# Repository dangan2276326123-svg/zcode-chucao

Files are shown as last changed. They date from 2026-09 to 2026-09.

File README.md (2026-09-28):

# 纯视觉芍药行间除草机器人

本项目为纯视觉（单目相机，无 RTK/激光雷达）芍药行间除草机器人的完整工程：包括 DeepLabV3+ 语义分割训练、相机标定与 IPM 逆透视变换、导航控制、上位机（PC）主控循环、车端（树莓派）桥接与下位机（STM32）固件。

## 逐文件说明

### 根目录

| 文件 | 说明 |
|---|---|
| `README.md` | 本文件：目录/文件说明 + 快速上手 |
| `AGENTS.md` | AI 协作（ZCode/Agent）工作约定 |
| `.gitignore` | git 忽略规则（视频、抽帧、标定图、权重、抽帧、标定图、权重等（Keil OBJ 编译产物已另行清理出库）） |

### `common/` — PC/车端共用的 Python 模块

| 文件 | 说明 |
|---|---|
| `protocol.py` | 串口通信协议（帧格式、CRC、命令字），与下位机 `firmware/protocol.c` 一一对应 |
| `uart_vectors.py` | 控制量/状态量的串口向量编解码 |

### `network/` — 深度学习与感知算法

| 文件 | 说明 |
|---|---|
| `train_m.py` | **主分割模型训练入口**（DeepLabV3+ MobileNetV2，960×720，二分类：背景/杂草） |
| `train_h.py` / `train_r.py` / `train_x.py` | 其他骨干/配置的实验训练脚本（h/r/x 变体） |
| `train_metric_log.csv`（及 `_backup`） | 训练过程指标日志 |
| `modeling.py` | DeepLabV3+ 模型组装（选 backbone、ASPP、解码器） |
| `_deeplab.py` | DeepLabV3+ 核心结构实现（ASPP、Decoder） |
| `backbone/mobilenetv2.py` | MobileNetV2 骨干（主用） |
| `backbone/resnet.py` | ResNet 骨干（备选） |
| `backbone/xception.py` | Xception 骨干（备选） |
| `backbone/hrnetv2.py` | HRNetV2 骨干（备选） |
| `camera_calib.py` | 相机标定适配器：加载 `data/calib_params.npz`，去畸变 + IPM 逆透视（输出 960×720 物理坐标掩码） |
| `nav_control.py` | 导航控制：行中心线偏差/航向误差 → 差速控制量 |
| `local_single_station.py` | 本地单工位端到端链路：标定→分割→后处理→IPM→控制，用于整链自测 |
| `predict_demo.py` | 单张/文件夹推理演示（可视化叠加） |
| `utils.py` | 数据集加载、指标（mIoU）、损失等训练辅助 |

### `pc/` — 上位机（笔记本电脑）主控

| 文件 | 说明 |
|---|---|
| `main.py` | **完整控制循环入口**：`--source` replay 模式 / `--live` 实车模式，GUI 叠加显示，ESTOP 急停联锁 |
| `replay.py` | 对视频/图片目录逐帧回放推理并保存结果（离线验证） |
| `perception.py` | 感知封装：加载权重与标定 → 去畸变 → 分割 → IPM 鸟瞰 → **导航线拟合**（远场 `peony_postprocess` + `fit_centerline_lsq_weighted` 给底盘导航；近场 `peony_postprocess` 给中间刀 PID） |
| `control.py` | 控制层 4 个纯 Python 类（无 torch/cv2 依赖，各带单元测试）：`MiddleToolPID` 近场横向误差 → 中间刀滑台偏移（条件积分抗饱和，输出限幅 ±50mm）；`LatencyCompensator` 链路时延估计（滚动 p50/p95）+ 误差前移补偿 err+rate·delay；`LatErrorRate` 横向误差变化率估计（有限差分 + 平滑，供上者）；`DifferentialDrive` 底盘差速：远场横向误差+航向阻尼 → 左右轮速 v∓dv（标称 0.14 m/s，限幅 ±0.2）。⚠️ 过渡态：实车有四轮转向伺服但固件在 AUTO 锁直，按纯差速走；四轮转向+差速混合重写未做（缺口清单 P0-1），电流前馈也未实现（F4） |
| `state_machine.py` | 作业状态机（待机/作业/掉头/急停等状态切换） |
| `status_rx.py` | MCU STATUS 接收（live 模式，UDP 9100）：坏帧捕获计数绝不裸抛（D7 约束），滚动 1 秒 ≥5 坏帧报警（多半是固件/Python 协议字段失同步）；纯逻辑类，socket 留在 main |
| `ipm_io.py` | **IPM 外参加载器（带来源校验）**：拒绝无来源字段、`points_source != field`、源图近乎纯色/全黑、重投影超 2 cm、点数 <4、**车辆档案不匹配**的标定文件。存在的原因：仓库里那份 `results/smoke_ipm/ipm_params.json` 看着像标定，其实源图全黑（mean=0/std=0），只是求解器的冒烟测试 |

### `vehicle/` — 车端（树莓派）

| 文件 | 说明 |
|---|---|
| `stream_pi.py` | 树莓派上抓取相机图像并回传给上位机 |
| `bridge.py` | PC ↔ 下位机桥接：把上位机控制量经串口转给 STM32，回传状态 |
| `config.yaml` | 车端配置（PI_IP、串口号等） |

### `tools/` — 数据处理脚本

| 文件 | 说明 |
|---|---|
| `bench_status.py` | **B1/B2 台架验收记录器**：收 MCU 的 STATUS 帧（UDP 9100，复用 `pc/status_rx.StatusReceiver`，与生产同一套新鲜度/乱序/重启重同步判据），按绝对时间戳把每帧、每次**模式跳变**、每段**静默 gap**（成对 gap_start/gap_end ＋ 时长）和**你敲的场景标记**写进同一张 CSV。用途是把"失联几秒停车、夺权后刀具动不动"这类几秒内的瞬时行为变成可回看的证据。⚠️ 它**不测**横向偏差的米制数值（感知侧占位几何未接线）；CSV 里的 `current_a`/`batt_v` 两列固件是占位值（`retrofit.c:226` 写死 48.0f），只能看趋势不能当实测。X5 侧 `vehicle/config.yaml` 的 `pc_ip` 必须指到本机，否则收不到帧——那不是 MCU 的错。 |
| `check_dataset.py` | 数据集完整性检查（图/mask 对齐、类别统计） |
| `json2mask.py` | 标注 JSON → 训练用灰度 mask |
| `morph_process.py` | 分割结果后处理 + **导航线拟合**（被 `pc/perception.py` 和 `network/local_single_station.py` 导入）：`extract_dual_walls` 从 IPM 鸟瞰掩膜提取左右垄墙 → `fit_centerline_lsq` 对双墙各拟合 x=a·y+b 取中点 → `fit_centerline_lsq_weighted` 裁剪最小二乘 + 按内点率加权融合（遮挡鲁棒，单墙退化时门控回退）→ 输出 lookahead 行的横向偏差 `center_x` |
| `split_dataset.py` | **数据集划分（分组模式）**：按 视频/地块/日期 前缀整组划分，杜绝邻帧跨集合（H1.3）；冻结 `split_manifest.json`；硬性保证 train/val/test 各≥1 组，组数 <3 直接拒绝而非静默退回逐图；源目录先校验后清空，`--force` 才清目标 |
| `check_doc_invariants.py` | **文档不变量检查器**：执行 AGENTS 审查清单第 2 条 b) 项的"全仓枚举圈号区间并打印命中数"。扫描范围按 09-22 定案**摘除审查清单第 2 条所在行块**（规则自己的反例举例不计入，否则它永远红）。退出码 0=干净／1=禁用语义命中／2=基线漂移需解释／3=有 md 读不进去（**读不到就不算零命中**，防止假通过）。数法按**出现次数**、不按行数，两者都印。 |
| `geometry_check.py` | **整车空间口径判据（只报事实，不报结论）**：要 N 把刀各进一条等距草带，车宽至少 `(N−1)·s + 刀宽`。`track_span` 给"轮距等于几个行距／离整行距还差多少／几何上是否可能对得上行"，**不输出压苗结论**——旧版那句"车宽>行距即压在作物行上"是 09-21 复审撤回的过度推论（行距 38.2 时轮距 191 恰为 5 个行距，两轮正落在行间）；判压苗要另量胎宽（M14）与轮迹对行线偏差（M15）。`slide_reach_verdict` 按"总行程 = 2 × 单侧需求"判够不够（旧实现拿总行程跟单侧比，会把 30 cm 报成够）。未实测的量返回"不下结论"，不补默认值。配合 `docs/整车尺寸实测表_20260921.md` |
| `pre_annotate.py` | **半自动预标注**（DeepLabV3+ → labelme JSON + 叠加目检图）：qoder 工作区版，缺依赖时打人话提示、输出默认锁在工作区内、打印权重 md5/mtime 与解释器路径。原脚本在只读仓 `chucao_prj/annotation_tools/`，不改它 |
| `启动预标注.bat` | 预标注启动入口（写死可用解释器）。**故意只写 ASCII**：.bat 里的中文必须 GBK 编码，否则 cmd 显示乱码 |

### 运行环境 — 用哪个解释器（09-21 实测，别再猜）

| 用途 | 解释器 | 已验证 |
|---|---|---|
| 训练 / 预标注 / 感知推理 | `D:\ruanjian\anac\envs\deeplab\python.exe`（conda env `deeplab`，Python 3.9.23） | numpy 2.0.2、cv2 5.0.0、torch 2.6.0+cu124、torchvision 0.21.0、albumentations 2.0.8；`pre_annotate.py` 跑通，设备 cuda |
| 同上（备用，`python` 在本机 PATH 里就是它） | `D:\ruanjian\anac\python.exe` | 352 张预标注全过，rc=0 |
| **只**用于打开 labelme 图形界面 | `chucao_prj\annotation_tools\labelme_env\Scripts\python.exe` | ⚠️ 该 venv **只有 labelme 5.10.1 + numpy**，没有 torch/albumentations/cv2 —— 拿它跑 `.py` 必然 `ModuleNotFoundError: No module named 'cv2'` |
| matplotlib 绑图 | ❌ 两个环境都不可用 | numpy 2.0.2 与已编译的 1.x 冲突（ImportError）。曲线改用 python-pptx 原生图表或 CSV |

**PyCharm 里"点运行没反应"的原因（09-21 实例）**：工程开成了父目录 `D:\JetBrains`。`D:\JetBrains\.idea\workspace.xml` 里运行配置数为 **0**，而 `pre_annotate` 那条配置存在 `chucao_prj\.idea\workspace.xml` 里并绑定 `<module name="chucao_prj"/>` —— **PyCharm 不加载嵌套子目录的 `.idea`**。正确做法：以 `D:\JetBrains\chucao_prj` 为工程打开（它自带 4 条配置与 deeplab SDK）。另：设置窗口未关闭时主窗口 ▶ 不响应。

### `firmware/` — 下位机固件（STM32F407，Keil）

| 文件/目录 | 说明 |
|---|---|
| `protocol.c/.h` | 串口协议实现（帧解析、CRC），与 `common/protocol.py` 对应 |
| `retrofit.c/.h` | 改造车控制逻辑（接收上位机指令驱动执行机构） |
| `集成说明.md` | 固件集成与烧录说明 |
| `大车/HARDWARE/retrofit/` | 上述 retrofit 模块在 Keil 工程内的副本 |
| `大车proj/大车/` | 完整 Keil uVision 工程：`USER/main.c` 主程序与中断；`HARDWARE/` 各外设驱动（PWM、电机 `bujin_motor`、`car_control`、`path_plan`、`sensor`、多路 `uart*`、`iic`、`CAN`、`ADC`、`LCD` 等）；`FWLIB/` STM32 标准外设库（官方库文件，不改动）；`OBJ/` 编译产物（.hex/.axf/.o，含可烧录的 `PWM.hex`）；`SYSTEM/` 延时/串口基础库；`keilkilll.bat` 清理编译产物脚本 |

### `hardware_ref/` — 硬件参考资料

| 文件/目录 | 说明 |
|---|---|
| `大板/` | 主控板 Altium 原理图（`407-cpu/io/power/exp/485.schdoc` 分图 + `大板.pdf` 合图 + `tianjin.PrjPcb` 工程） |
| `大车firmware/` | 改造前原车固件（参考用，勿改动） |

### `data/` — 数据

| 文件/目录 | 说明 |
|---|---|
| `calib_params.npz` | 相机标定结果（1920×1080 原始内参/畸变系数），被 `network/camera_calib.py` 和 `pc/perception.py` 加载 |
| `videos/field_video1~3.avi` | 田间原始视频（共 2.8 GB，已 gitignore，仅存本地） |

### 其他目录

| 目录 | 说明 |
|---|---|
| `avi_frames/` | 田间视频抽帧结果 `img_XXXXXX.jpg`（295 张 1920×1080，已 gitignore） |
| `calib_imgs/` | 标定棋盘格照片 `IMG_XXXX.jpg`（已 gitignore） |
| `model_data/weights/` | 训练权重 `best_model.pth`（已 gitignore）。⚠️ 与只读仓 `chucao_prj/model_data/0.7428m/best_model.pth` **同大小不同 md5**（`32da179c…` vs `cdd22733…`），不是同一个 checkpoint，引用前必须点名 |
| `results/smoke*` | 冒烟测试输出：标定/去畸变/推理样例图与 `run_log.csv` |
| `tests/` | **13 个测试文件，`python -B -m pytest tests/ -q` = **150 passed（09-28 实测）**。逐个：`test_protocol.py` 协议编解码/CRC 向量（**不含** C 对拍，那要台架 B2）；`test_control.py` 控制量与跨边界拆帧；`test_status_rx.py` STATUS 坏帧/新鲜度/MCU 重启重新同步；`test_nav_geometry.py` 前轮 Ackermann 几何（直行极限/后轮零角/共 ICC/刚体速度/镜像）；`test_mjpeg.py` TCP 流解析 + 有界读流 `StreamFeed`（含"connect 卡住也不拖住控制循环"）；`test_adaptive_walls.py` 自适应双墙；`test_perception_norm.py` 感知归一化；`test_data_tools.py` 资产安全 + 分组划分（含"文件名没带批次号 → 整批塌成一组"的命名陷阱）；`test_geometry_check.py` 空间口径判据（**只测事实与单位，不测物理结论**）；`test_ipm_io.py` 标定来源校验＋跑真实 solve() 的闭环；`test_pre_annotate.py` 预标注护栏（含"人工改过后重跑仍保留"）；`test_bench_status.py` 台架状态记录器（字段名必须与生产解析器一致、模式跳变单独成行、静默段成对落账；含 09-28 那条盲点回归——**报文一直到达但全被拒收时也必须记 gap**，因为 MCU 重启后序号回退正好就是这个样子）；`test_doc_invariants.py` 文档不变量检查器本身（钉住两条容易做错的语义：规则自己举的反例不计入扫描、基线按出现次数而非行数） |
| `docs/缺口清单.md` | **项目"欠账台账"**：顶部『📊 总览：做完的/没做的』板为进度权威，逐项含做法/验收/耗时/依赖 |
| `docs/参数差异台账.md` | **硬件/参数事实的唯一权威**（Hw/Fw/Pc 项 + 改一笔记一笔）。当前到 Hw-19 |
| `docs/决策依据说明.md` | 设计决策记录（D1–D8）。⚠️ D8"实车无转向执行器"已作废未标，见台账 Hw-13 |
| `docs/接线图_v1.md` | 大板接线图 v1（含 §4A 待改项） |
| `docs/车上供电与接线清单.md` | **供电与接线权威版**（方案 B 定稿 v4，198 行，采购详版，09-12） |
| `docs/车上供电与接线清单_v1.md` | 同上早期版（119 行，09-12 16:49），**已存档**，以 v4 为准 |
| `docs/X5验机与接入执行清单.md` | RDK X5 到货验机四项与接入步骤 |
| `docs/秋季图像采集清单.md` | 秋季采集执行文档（矩阵、命名、标注规范、IPM 顺带标定） |
| `docs/整车尺寸实测表_20260921.md` | **M1–M12 量车型**：每项给测法、照片留档与"这个数用来判什么"；判据在 `tools/geometry_check.py` |
| `docs/thesis_text_fixes_R7_H4.md` | 论文正文修改单（R7/H4 对应项） |
| `docs/大板实物标注.jpg`、`近照A/B/C标注.jpg` | 主控板实物照（13 处编号标注）。**全仓无整机/刀架/电推杆照片**——见量车型 |
| `docs/组会汇报_20260907/`、`docs/组会汇报_20260916/` | 组会 deck（Route C 可编辑 pptx + plan JSON + 证据合同 `paper_analysis.json` + `gen_map.py` 生成的溯源表 + 渲染 QA 图） |
| `docs/纯视觉…实施方案_v0.4~v0.7.docx` | 历史总体方案 docx（**已被 md 版方案取代**，见下） |
| `docs/refs/` | 调研原始记录（访谈 raw、原理图核对、参考资料调研、方法章理论材料） |
| `docs/superpowers/specs/2026-09-16-v1.0-system-validation-design.md` | **现行方案**（整机设计与田间系统验证；V1–V4 真值、P/E 修复区、两道准入门） |
| `docs/superpowers/specs/2026-09-08-v0.9-defense-first-design.md` | 已被 v1.0 取代（顶部有横幅），保留作决策史 |
| `docs/superpowers/specs/2026-09-09-4ws-steering-design.md` | 4WS 转向设计稿 |
| `docs/superpowers/specs/2026-08-14-peony-interrow-weeder-design.md` | 最早的系统设计稿 |
| 外部评审件 | 在 **`D:\ai work\codex\docs\reviews\`**（不在本仓）：09-09 整体审查、09-14 复审、09-15 论文聚焦复审、09-21 增量复审 |

## 快速上手

> 解释器见上面「运行环境」表：训练与预标注用 `D:\ruanjian\anac\envs\deeplab\python.exe`（或 PATH 里的 `D:\ruanjian\anac\python.exe`）；**别用 `labelme_env`**。
> 权重默认 `model_data/weights/best_model.pth`，标定文件 `data/calib_params.npz`。

### 标注 → 划分 → 训练（C1/C2 链路，**逐步可执行版**）

> 这一段 09-21 复审指出两处会真出事的接口错配，已改：① 旧示例从 `raw/` 划分，
> 但人工修正后的 JSON 在 `pre_annotated/labelme/`，从 `raw/` 划分等于**把人工成果丢掉**；
> ② `split_dataset.scan_pairs()` 只按 `.jpg` 配对，而 `pre_annotate` 接受 PNG/BMP，
> 非 `.jpg` 的图**不会进训练集**（预标注脚本现在会打这句警告）。

```bash
PY=D:/ruanjian/anac/envs/deeplab/python.exe     # 见上面「运行环境」表，别用 labelme_env

# 0) 采集原图放这里。**文件名首段就是分组键**（默认按 _ 切）：
#    t01_0928_0001.jpg → 组 t01。一组 = 一段连续拍摄/一块田/一天。
#    ⚠️ 别用 IMG_0001.jpg 这种全局序号名——每张都切出 IMG，整批塌成 1 组，
#       独立测试集直接不存在（脚本会拒绝，但那是白跑一趟）。见采集清单 §6
#    分组决定 train/val/test 的边界，同一组绝不跨集合（H1.3）
ls data/autumn_data/raw | head

# 1) 半自动预标注：先 --limit 3 小批试跑
$PY tools/pre_annotate.py --input data/autumn_data/raw \
    --output data/autumn_data/pre_annotated --limit 3
#    产物：pre_annotated/labelme/{同名 .jpg + 同名 .json}   ← labelme 要求图与 JSON 同目录
#          pre_annotated/check/check_*.jpg                ← 机器草稿叠加图，仅目检用
#          pre_annotated/重点检查清单.txt                  ← 前景占比异常/无多边形，优先人工复核
#    ⚠️ 重跑同一目录**默认跳过已存在的 JSON**（里面可能有人工修正）。
#       确实要推倒重做才加 --overwrite；同名不同扩展（a.jpg + a.png）直接拒绝。

# 2) 人工复核：labelme 打开 pre_annotated/labelme/（不是 raw/，也不是 check/）
#    labelme 只用于**打开图形界面**时才用 labelme_env 的解释器。
#    标签必须落在冻结字典内（默认写 shaoyao），否则第 5 步严格模式报错。

# 3) 划分：--source 指人工定稿所在的 labelme 目录，不是 raw
$PY tools/split_dataset.py --source data/autumn_data/pre_annotated/labelme \
    --out-root model_data --dry-run        # 先看组数与三集合分配
$PY tools/split_dataset.py --source data/autumn_data/pre_annotated/labelme \
    --out-root model_data --force          # 分组不足 3 组会直接拒绝，不再静默退回逐图
#    产物：model_data/{train,val,test}/images/{.jpg,.json} + 空的 masks/
#          model_data/split_manifest.json   ← 分组已冻结，训练与复核都以它为准
#    ⚠️ --force 会清空目标目录；源目录与输出目录重叠时脚本会拒绝（R2 修复）

# 4) 生成 mask：split 只建空 masks/ 目录，要自己跑 json2mask（三个集合各一次）
for s in train val test; do
  $PY tools/json2mask.py --input model_data/$s/images --output model_data/$s/masks
done
#    全背景掩码会单独点名（多半是标签名不在冻结字典里或该图未标注）

# 5) 训练
$PY network/train_m.py                     # 读 model_data/{train,val,test}/{images,masks}
```

**口径提醒（复审 §6）**：训练集可以用模型预标注再人工修正，但**评价用的真值要独立制作并复核**。
看过算法输出、只纠正了几处明显错处的草稿，不能当无偏真值；
S0 用来调阈值的数据也要与最终留出评价分开记用途。

### 回放推理（离线验证整条链路）

```bash
python pc/main.py --source data/videos/field_video1.avi          # 完整控制循环（replay 模式）
python pc/replay.py data/videos/field_video1.avi --step 15       # 仅回放推理并保存结果
```

### 实车运行

```bash
python pc/main.py --live --pi-ip 192.168.127.10 --stream-host 192.168.127.10 --stream-port 5000
```

> ⚠️ 两条硬禁令仍然有效：**禁止实车 AUTO、禁止按现有接线文档带动力接线**（解除条件见 `docs/缺口清单.md` 门 N／门 F）。

### 测试

```bash
python -B -m pytest tests/ -q        # 09-28 基线：150 passed
python -B tools/check_doc_invariants.py   # 圈编号/交叉引用全仓枚举；exit 0 才算干净
```

## 数据流

田间视频（`data/videos/`）→ 抽帧（`avi_frames/`）→ **`tools/pre_annotate.py` 半自动预标注**（labelme JSON + 叠加目检图）→ **在 `pre_annotated/labelme/` 里用 labelme 人工复核修正**（重跑预标注默认跳过已有 JSON，不覆盖人工成果）→ `tools/split_dataset.py` **分组划分 + 冻结 `split_manifest.json`**（`--source` 指人工定稿目录，不是 `raw/`）→ `tools/json2mask.py` 按集合转 mask → `network/train_m.py` 训练 → 权重（`model_data/weights/`）→ `pc/main.py` 感知（去畸变/标定 → 分割 `network/` → IPM 鸟瞰（⚠️ 现在仍是 `perception.py` 里的**占位几何**；`pc/ipm_io.py` 这个带来源校验的加载器**还没有调用方**，接线属 E2③ 未完项）→ **`tools/morph_process.py` 双墙提取 + 最小二乘导航线拟合**：远场线给底盘、近场线给中间刀）→ `pc/state_machine.py`/`pc/control.py` → 串口协议（`common/protocol.py` ↔ `firmware/protocol.c`）→ 车端网关（RDK X5，`vehicle/`）→ STM32 固件（`firmware/`）驱动执行机构。

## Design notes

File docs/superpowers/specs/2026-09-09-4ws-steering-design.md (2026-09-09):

# 全 4WS 转向改造设计(固件 / 算法 / 协议 / 论文)

> 日期:2026-09-09
> 状态:设计稿,待作者复核
> 工作区:zcode(唯一开发区;论文改动同步至 chucao_prj 的 thesis_cau)
> 前置:v0.8/v0.9 方案 §3.1(已定论:按实车固件为准 → 真 4WD-4WS);作者已选定主工作模式 = **全 4WS**(四轮独立转角按 Ackermann 几何分配)
> 证据:`firmware/大车proj/大车/USER/main.c:519-532` 存在 `send_angle(1..4)` 四路转向舵机链路;AUTO 模式 `angle[]=0` 锁死走差速,即"有转向机构而不用"。

---

## 0. 问题定义

三层各错各的:

1. **硬件**:实车为 4WD-4WS(UART4 @19200 舵机总线,四轮独立偏转,有零位标定 `wheel_Angle_correct[]` 与转角限幅 `flag_steer_limit`)。无争议。
2. **代码**:固件 AUTO 把 `angle[0..3]` 强制清零(差速);PC 端 `network/nav_control.py` 的 `Ackermann4WS.compute()` 按 4WS 几何输出却无处可去;v0.7 曾要求算法改差速输出(理由"无转向执行器"系事实错误,撤回)。
3. **论文**:chucao_prj `thesis_cau` ch02"转向不设转向机构"、ch04 滑移转向运动学、D8"实车没有转向轮偏转执行器"——与开题承诺(四转向轮期望偏角)冲突,答辩裂缝。

## 1. 协议:新增 NAV2(type 0x11)

- 帧格式不变(`0xA5 0x5A | len | type | seq | payload | crc16`),新增 `TYPE_NAV2 = 0x11`。
- payload(21 字节):`δ_fl, δ_fr, δ_rl, δ_rr`(f32le,rad,+左)、`v`(f32le,m/s)、`flags`(u8)。
- **旧 NAV(0x01)保留**为差速兼容模式:固件收到旧帧按左右轮速对处理(v0.7 语义),回放/仿真可渐进迁移。
- 合法域:|δ| ≤ `max_steer`(取舵机机械限幅,台架标定后写入配置,初值 0.35 rad);|v| ≤ 1.0 m/s。超限值由固件钳位并置 flags 错误位回 STATUS。
- **桥接端(RDK X5)零改动**:`vehicle/bridge.py` 对帧类型透明(仅校验后转发),NAV2 直接通过。顺带修正 `bridge.py`/`stream_pi.py` 注释中"Raspberry Pi"→"RDK X5"。

## 2. PC 算法(network/nav_control.py)

- `KalmanLateral`、`PDController` 不动;`Ackermann4WS.compute(steer_center, v)` 恢复为唯一出口(此前按 v0.7 要求改差速的步骤不再执行)。
- 出口链:`PD 输出 steer → Ackermann4WS.compute → pack_nav2(δ×4, v, flags)`。
- E-STOP/视觉丢失行为不变(停发 NAV2 → 固件 500 ms 看门狗接管)。
- `common/protocol.py` 增加 `TYPE_NAV2`、`pack_nav2/unpack_nav2` 及已知向量 pytest;旧 `pack_nav` 保留并标注 deprecated。

## 3. 固件(大车工程 + retrofit.c)

- **撤锁**:删除 `main.c:519-521` 的 AUTO `angle[]=0` 强制清零。改为:MODE_AUTO 下每周期把 NAV2 目标角经 **slew-rate 限幅**(复用既有 safety gate 的限速路径)写入 `angle[]`,由原 `send_angle` 链路下发;四轮速度目标由 `v` 按 Ackermann 内外侧差分配(`Ackermann4WS.compute` 已输出该分配),进现有 PID 速度环。
- **旧 NAV 兼容**:收到 0x01 时保持现行差速逻辑(不写 `angle[]`)。
- **转向失效检测(新增,4WS 特有故障面)**:利用现有 `AD_angle[4]` 反馈,`|反馈角 − 指令角| > 阈值`(初值 5°,台架标定)持续 >300 ms → 判转向失效 → 减速 + 提刀 + 停车,走既有降级路径;事件写入日志帧。
- 看门狗/ESTOP/心跳语义全部不变。

## 4. 台架验证顺序(目标:2026 年 11–12 月完成,勿压到 2027 年 1 月)

1. 四轮零位重标(`wheel_Angle_correct`),台架;
2. **指令-反馈阶跃测试**:±5°/±10° 阶跃,记录响应滞后、稳态误差、超差率——这是"舵机品质能否支撑横向偏差 ≤±5 cm"的判据,亦是退路触发条件;
3. NAV2 帧回放驱动台架联动(含转向失效注入:人为断一路舵机反馈);
4. 通过后才进整车联调;不达标即触发退路:作业模式降为"小角度转向 + 差速纠偏",论文如实写"车具备 4WS,本作业模式选择小角度转向",**严禁再写"无转向机构"**。

## 5. 论文(chucao_prj / thesis_cau,不依赖春季试验,可先行)

- ch02 平台节:"无转向机构"→ 4WD-4WS 参数表(舵机路数、UART4、转角范围);
- ch04 运动学小节:滑移转向 → 4WS Ackermann + ICC 几何推导(`nav_control.py` 注释内推导可作底稿),时延补偿推导不受影响;
- D8 决策记录按"结论/被否备选/理由/证据/推翻条件"格式重写(v0.7 版的"理由"列含事实错误,整条作废);
- 增加与开题"四转向轮期望偏角"承诺的呼应句,与 v0.8 §3.2 的"林下→大田"显式调整声明同节出现。

## 6. 完成定义

- pytest:NAV2 pack/unpack 已知向量、钳位、旧 NAV 兼容路径通过;
- 固件:撤锁后 Keil 0 错误;slew 限幅与转向失效检测有台架记录(阶跃曲线 + 失效注入视频/日志);
- 论文:ch02/ch04/D8 三处改毕,grep 全库无"滑移转向/无转向机构"残留(除显式调整声明)。

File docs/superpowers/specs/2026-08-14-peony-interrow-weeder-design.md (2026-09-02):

# 纯视觉芍药行间除草机器人 项目计划书（草案）

> 状态：草案，等待用户确认
> 日期：2026-08-14
> 版本：v0.1

## 1. 项目概述与目标

研制一台面向芍药栽培的纯视觉行间除草机器人样机：

- 底盘跨 4 行芍药带作业，一次通过同时清除 3 条草带（3 个行间通道）；
- 全程不依赖 GNSS/RTK，导航与控制完全基于车载单目相机；
- 采用机械中耕除草，不使用化学药剂，满足中草药零农残要求；
- MVP 目标：0.5 km/h 稳定作业、单日有效作业面积 3 亩、药苗损伤率 ≤1%；
- 前期为科研样机与田间验证，后期再考虑商用化。

## 2. 需求基线（已与用户确认）

| 项 | 结论 |
| --- | --- |
| 项目性质 | 前期科研样机 + 田间验证，后期商用 |
| 作业范围 | 仅行间除草，不做株间 |
| 种植模式 | 底盘跨 4 行芍药，除 3 条草带 |
| 草带行距 | 40-50 cm，轮距与刀具间距可机械调整 |
| 刀具方案 | 3 把除草刀；外侧两把固定（手动丝杠调距），中间一把按导航线主动左右微调，用于对比试验 |
| 地形土壤 | ≤15° 坡，壤土 |
| 效率 | ≥0.5 km/h，单日 ≥3 亩 |
| 除草原理 | 机械中耕 |
| 深度控制 | 被动仿形，限深轮 + 弹簧浮动，深度 2-4 cm 可调；主动电控留二期 |
| 安全机制 | 全部纳入 MVP：硬件急停、限深轮触地/过载检测、视觉丢失自动提刀停车、行端自动提刀 |
| 感知 | 单相机 |
| 算力架构 | 算力在电脑端；车端只保留 MCU + 树莓派（图像编码回传 + 串口网桥） |
| 无线链路 | 由本计划推荐并确认 |
| 时间/预算 | 压缩成本与周期，暂不考虑商用化 |

## 3. 开源方案调研与借鉴

### 3.1 高价值参考方案

| 项目 | 亮点 | 可复用 | 避坑 |
| --- | --- | --- | --- |
| Feldfreund DevKit ROS（Zauberzeug，MIT） | 商业级开源除草平台控制栈，ESP32 机器人脑 + ODrive + 急停 + GNSS + 相机 + Foxglove 远程监控 | “MCU 硬件抽象 + 急停/碰撞 + 无线监控”分层架构；安全状态机思路 | 绑定 ESP32/Lizard/ODrive 全家桶，直接抄代码收益低；建议只借鉴分层 |
| Nindamani（AutoRoboCulture，MIT） | NVIDIA AI Edge 冠军，ROS2 + Jetson Nano + 分割 + 机械除草 | “视觉感知→机械执行→无线通讯”闭环组织方式；机电接口划分 | Jetson Nano 与 ROS2 Dashing 已过时；机械臂逐株除草吞吐太低，不适合行间连续作业 |
| OpenWeedLocator（OWL，MIT） | 489 星，低成本相机杂草检测 + 继电器触发执行器，树莓派 | 低算力视觉 + 执行器触发模式；文档与测试体系 | 绿度检测在“芍药绿 vs 杂草绿”同色场景不可靠；面向喷药场景，不直接适用 |
| FarmBot 全家桶（MIT） | Pi + Arduino 分层、MQTT、Web App、工具快换 | 车-电脑通信协议分层；工具挂接/快换思路 | 龙门架结构不适用于田间移动底盘；CNC 精度思路不能直接搬到农田 |
| PRBonn DG-CWS / CropAndWeed | 作物/杂草分割域泛化与公开数据集 | 若未来需要区分杂草，可迁移预训练 | CC BY-NC 非商用许可，商用前需替换/自采数据 |
| petern3/crop_row_detection（GPL-3.0） | 经典 OpenCV 行线检测 | 导航兜底算法，模型失效时的降级策略 | GPL 传染性，商用需替换实现 |

### 3.2 调研结论

- 行间机械除草是目前唯一同时满足“效率、成本、零农残、低损伤”四条约束的成熟路线；激光除草成本与安全门槛高，机械臂逐株除草效率不足，均不适合本项目 MVP。
- 本项目最独特的组合点不在单点算法，而在“三草带并行 + 中间刀具主动对行 + 单相机 + PC 远程计算”的系统集成，这也是论文创新点的来源。
- 已存在代码（DeepLabV3+ 分割、IPM、双墙中心线、Kalman/PD、4WS 阿克曼、STM32 串口协议）应尽量复用，避免引入 ROS2 导致返工。

## 4. 技术选型与原因

### 4.1 除草机构：鸭掌铲式中耕刀 ×3

选型方案：

- 每把刀采用鸭掌铲（sweep）刀片，安装在三段独立刀梁上；
- 外侧两把刀梁：手动丝杠调距，作业中固定；
- 中间刀梁：加装横向直线滑轨 + 丝杠/步进电机，由视觉导航线闭环微调；
- 每段刀梁带独立限深轮与提刀执行器。

原因：

- 鸭掌铲在 2-4 cm 浅耕下切草根、翻土覆盖，结构简单、成本低、牵引阻力小，适合壤土与 0.5 km/h 低速；
- 被动刀具无需额外动力源，降低车端电气复杂度与故障点；
- 三段独立刀梁保证单刀过载或遇障时互不影响，且满足“中间主动、外侧固定”的对比试验需求；
- 中间刀主动对行只要求 ±2-5 cm 微调行程，丝杠+步进电机即可满足，避免昂贵的电动缸或液压系统。

### 4.2 入土深度控制：被动仿形（限深轮 + 弹簧浮动）

方案：

- 每段刀梁采用平行四连杆挂接，限深轮贴地，弹簧提供下压力；
- 深度 2-4 cm 通过丝杠限位手动调节；
- 限深轮设置触地行程开关，作为深度异常检测输入。

原因：

- 被动仿形结构简单、可靠、成本低，随地形起伏保持刀尖与地表距离稳定；
- 5-15° 坡地低频起伏由弹簧浮动吸收，无需实时闭环；
- 主动电控深度在 MVP 中收益低、成本高，留二期。

### 4.3 安全机制（全部入 MVP）

1. 硬件急停：车端急停按钮 + PC 端软急停，切断驱动与刀具动力；
2. 限深轮触地/过载检测：行程开关或微力传感器，异常时报警并提刀；
3. 视觉丢失自动提刀停车：PC 检测到分割置信度低或链路超时，立即发送提刀+停车指令；车端 MCU 心跳看门狗兜底（超过 300-500 ms 无有效心跳自动停车提刀）；
4. 行端自动提刀：检测到行尾/无行墙时自动提刀，人工确认后掉头；
5. 机械过载保护：刀梁装剪切销或弹簧脱开机构，防止撞石损坏底盘。

原因：

- 药苗损伤率 ≤1% 是硬指标，任何单点失效都必须有机械或电气兜底；
- “PC 软保护 + MCU 硬看门狗”双通道符合功能安全的分层思路，且不增加昂贵安全 PLC。

### 4.4 视觉感知：单相机双任务

方案：

- 保留前视单目相机（现有 1920×1080，已标定），安装位置保证视场覆盖 4 行芍药；
- 复用 DeepLabV3+ MobileNetV2 二分类分割（芍药行墙/背景），不增加杂草分类；
- 后处理从“双墙中心线”扩展为“四行墙 + 三草带中心线”：
  - 远场 ROI：生成三草带导航中心线，供底盘导航与中间刀预瞄；
  - 近场 ROI（刀具所在横向位置）：计算中间草带中心相对刀具的横向偏差，作为中间刀微调控制输入；
- 视觉置信度、无行墙状态作为提刀/停车信号。

原因：

- 行间机械除草不需要逐株识别杂草：整条草带都是作业对象，刀具靠行墙边界避让芍药，天然规避“同类绿”识别难题；
- 单相机同时承担导航与刀具对行，省掉第二路相机与标定，符合低成本要求；
- 二分类模型现有 mIoU 约 0.74，训练数据已存在，只改后处理与控制层，改动面最小。

### 4.5 计算架构：车端最小化，PC 集中计算

方案：

- 车端：STM32（已有，负责底盘驱动、刀具执行、安全看门狗）+ 树莓派（H.264 硬件编码回传图像、UDP↔串口桥接）；
- PC 端：运行现有 Python 视觉栈（分割、IPM、三带中心线）、导航控制器、中间刀控制器、GUI；
- 无线链路同时承载：视频流（PC 接收）、控制帧（PC 下发）、遥测/状态（双向）、心跳（双向）。

原因：

- 现有全部算法与训练流程都在 PC/GPU 上，车端只做采集与执行可避免移植和量化开销；
- 树莓派只做硬件编码与网络桥接，不跑推理，成本低且负载轻；
- 算力集中 PC 便于调试、采集数据、写论文实验。

### 4.6 无线链路：5 GHz Wi-Fi 点对点 + H.264/UDP/MQTT

选型：5 GHz Wi-Fi（802.11ac/ax），PC 侧或车端一侧作 AP，距离 50-150 m；视频用 H.264 低延迟 RTP/UDP，遥测与状态用 MQTT/WebSocket，控制用自定义 UDP 帧（CRC + 序号），心跳看门狗。

原因：

- 需要回传 720p/25-30 fps 图像，带宽需求约 2-4 Mbps，5 GHz Wi-Fi 足够且时延 <50 ms；
- 4G/5G 有资费与公网时延，LoRa/电台带宽不足传视频；
- 60 GHz（WiGig）带宽最高但距离短、怕遮挡，不适合田间；
- 一条 Wi-Fi 链路同时传视频与控制，车端只需要树莓派一个无线口，符合“车端最小化”。

### 4.7 控制系统

- 底盘导航：沿用现有 Kalman 横向滤波 + PD + 4WS 阿克曼 + STM32 串口帧协议，将串口帧改为 UDP 帧封装；
- 中间刀对行：以近场草带中心偏差为输入，位置式 P/PID 控制步进电机驱动丝杠滑轨，行程 ±5 cm；
- 模式切换：手动/自动/提刀/急停状态机，由 PC GUI 与硬件急停共同驱动。

## 5. 系统框架与数据流

```text
┌────────────── 田间车端 ──────────────┐        ┌──────────── 电脑端 ────────────┐
│ 相机 → 树莓派(H.264编码)             │ 5GHz   │ 解码 → DeepLabV3+ 分割         │
│ STM32: 底盘驱动/刀具/限深/安全看门狗  │ Wi-Fi  │ IPM → 四行墙 → 三草带中心线    │
│ 中间刀: 步进电机丝杠滑轨             │◄──────►│ Kalman+PD 导航 / 中间刀 PID    │
│ 限深轮: 行程开关/过载保护            │ 视频+  │ GUI: 监控/参数/软急停/模式切换  │
│ 提刀执行器 ×3 + 硬件急停             │ 控制+  │ 数据记录（论文实验）           │
└─────────────────────────────────────┘ 遥测+  └────────────────────────────────┘
                                       心跳
```

数据流（50-100 ms 闭环）：

1. 相机 → 树莓派 H.264 编码 → Wi-Fi → PC 解码；
2. PC 推理分割 → IPM → 四行墙/三草带中心线 → 近场刀具偏差；
3. PC 计算底盘转向与中间刀偏移 → UDP 控制帧 → 树莓派 → STM32；
4. STM32 执行并回报状态/传感器 → 树莓派 → PC；
5. 任一环节超时或置信度低 → 提刀 + 停车。

时延预算：采集 5-10 ms + 编码 5-15 ms + Wi-Fi 5-20 ms + 解码/推理 20-40 ms + 控制 5 ms ≈ 50-90 ms，对应 0.5 km/h 下 0.7-1.3 cm 位移，满足行间导航与 ±2 cm 对行要求。

## 6. MVP 范围

### 6.1 包含

- 三刀机械中耕机构（鸭掌铲 + 独立刀梁 + 限深轮 + 弹簧浮动）；
- 中间刀主动对行（丝杠滑轨 + 步进电机 + 视觉闭环）；
- 单相机四行墙/三草带感知；
- 现有底盘导航闭环接入；
- 车-电脑 5 GHz Wi-Fi 图传与控制链路；
- 全套安全机制（硬件急停、触地/过载、视觉丢失提刀、行端提刀）；
- PC 监控 GUI 与数据记录；
- 田间验证：除草率、药苗损伤率、横向偏差、效率、中间刀 vs 外侧固定刀对比。

### 6.2 不包含（二期）

- 株间除草；
- 自主头地转弯与全场路径规划；
- 杂草识别与选择性除草；
- 主动电控深度/力控；
- GNSS/RTK 融合；
- 多田块/多作物泛化与商用化。

## 7. 开发顺序与里程碑

| 阶段 | 内容 | 建议周期 |
| --- | --- | --- |
| M0 机构与硬件 | 三刀梁、丝杠调距、中间刀滑轨、限深轮、提刀执行器、安全机构；底盘轮距调整；相机安装与标定 | 3-4 周 |
| M1 通讯链路 | 树莓派 H.264 编码回传；UDP 控制帧；心跳/看门狗；PC 解码与 GUI 原型 | 2-3 周 |
| M2 感知与控制 | 四行墙/三草带后处理；近场刀具偏差；中间刀 PID 台架验证；导航闭环复测 | 3-4 周 |
| M3 整机联调 | 三刀机械中耕、提刀/安全逐项验证；0.5 km/h 直线作业；软硬件联调 | 3-4 周 |
| M4 田间试验 | 除草率/损伤率/偏差/效率数据采集；中间刀 vs 固定刀对比；论文实验数据整理 | 3-4 周 |

合计约 14-19 周（4-5 个月），若每周投入 2-3 人日，可在毕业前完成闭环。

### 7.1 低成本预算（估算）

- 树莓派 4B/5 + 电源/外壳：约 500-800 元；
- 5 GHz 无线网卡/AP + 天线：约 300-600 元；
- 三刀梁/鸭掌铲/限深轮/连接件：约 1500-3000 元；
- 中间刀丝杠滑轨 + 步进电机 + 驱动：约 500-1000 元；
- 提刀执行器 ×3 + 传感器/行程开关/急停：约 1000-2000 元；
- 相机支架、标定板、线束、杂项：约 500-1000 元；
- 合计约 0.5-1 万元（底盘、STM32、相机、PC 已有）。

## 8. 论文创新点（候选）

创新点 1：面向“四行三带”种植模式的多草带并行机械除草与中间刀具视觉主动对行方法

- 单相机语义分割提取四行芍药墙，同时生成三条草带中心线；
- 外侧两刀被动/固定作业，中间刀依据近场导航线实时横向微调，形成“三刀并行、一主动两被动”的作业模式；
- 与固定刀进行田间对比，量化主动对行对药苗损伤率与除草均匀性的改善。

创新点 2：车-电脑无线分布式低成本视觉架构与多级安全联锁

- 车端仅保留 MCU + 树莓派（H.264 编码回传 + 串口网桥），算力集中在 PC；
- 视频/控制/遥测/心跳共用一条 5 GHz 链路；
- 形成“PC 软保护（置信度/链路超时）+ MCU 硬件看门狗 + 机械限深/过载保护”三级安全联锁，保障药苗损伤率 ≤1%。

## 9. 风险与对策

| 风险 | 影响 | 对策 |
| --- | --- | --- |
| 无线图传时延波动导致控制不稳 | 导航/对行超调 | 视频降到 720p/25fps，控制帧与心跳独立小包高频发送；必要时 5 GHz 定向天线 |
| 行墙分割在强光/阴影下失效 | 停车频繁 | 复用现有训练集 + 补充恶劣光照样本；经典 OpenCV 行线检测兜底 |
| 三刀同时过载/卡滞 | 机构损坏 | 独立剪切销/弹簧脱开 + 限深轮触地检测 + 提刀 |
| 中间刀微调响应不足 | 对行偏差大 | 提前预瞄（远场中心线 + 运动学前馈），行程 ±5 cm 留裕量 |
| 试验周期不足 | 论文数据不完整 | 先台架验证中间刀控制，田间只做三组重复对比 |

## 10. 验收指标（MVP）

- 行间除草率 ≥80%（前后杂草覆盖率对比）；
- 药苗损伤率 ≤1%；
- 底盘横向偏差 ≤±5 cm（远场），中间刀对行偏差 ≤±2 cm（近场）；
- 作业速度 ≥0.5 km/h，单日 ≥3 亩；
- 视觉丢失/链路超时自动提刀停车 ≤1 s；
- 完整记录中间刀主动 vs 固定刀对比数据。

## 11. 待确认事项

1. 无线链路采用“5 GHz Wi-Fi 点对点 + H.264/UDP/MQTT/心跳”是否确认；
2. 除草刀具采用鸭掌铲、中间刀丝杠+步进电机 ±5 cm 行程是否确认；
3. 相机安装位置（前视低机位，视场覆盖 4 行）是否可落实；
4. 预算 0.5-1 万元与 4-5 个月周期是否可接受；
5. 创新点按第 8 节两条撰写是否合适。

确认后，下一步进入 writing-plans，输出可执行的实施计划（任务拆分、依赖、每周检查点）。

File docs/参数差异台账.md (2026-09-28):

# 实车参数 vs 固件/PC 参数差异台账

> 用途:用户已确认**真实除草车与固件内参数存在出入**。本表把固件/PC 里所有"拍脑袋或占位"的参数集中登记,实车测量后填入"实车实测值",批准后改代码并在"状态"列记录。
> 规则:**每改一个参数 = 改代码 + 改本表 + 重编译/重跑测试**,不留暗改。台架标定操作细则见 `docs/缺口清单.md` B4。

## 1. 固件参数(firmware/retrofit.c)

| # | 参数 | 位置 | 固件现值 | 含义 | 实车实测值 | 测法 | 状态 |
|---|---|---|---|---|---|---|---|
| Fw-1 | `STEPPER_STEPS_PER_MM` | retrofit.c:15 | **25.0** | 步进每毫米脉冲数 | ______ | 台架发 TOOL 帧 ±20mm,百分表量位移反算;10 次往返重复定位 ≤0.5mm;驱动器细分数变了要重标 | 🔴 待实测 |
| Fw-2 | `STEPPER_PULSE_HZ` | retrofit.c:16 | **2000** | 步进最高脉冲频率 | ______ | 从低速试起,失步即降 | 🔴 待实测 |
| Fw-3 | `c_per_pulse` | retrofit.c `wheel_speed_update` | **0.0005** | 霍尔脉冲→轮速换算(m/s per pulse) | ______ | 顶起车轮手转整 N 圈,对 PC 收到的速度积分路程;或拖行 10m 实测,误差 ≤5% | 🔴 待实测 |
| Fw-4 | AD5 电流换算系数 | retrofit.c `adc_current_a()` | **返回 0(占位)** | ACS712-05B 电机电流(A) | ______ | 万用表串入 MOTOR_2 回路对照 AD5 读数线性拟合(灵敏度 185mV/A,减静态偏置);读取代码要接 iic.c 的 U18 ADS1115 | 🔴 占位,必须改 |
| Fw-5 | 电池电压 | retrofit.c STATUS 组帧 | **固定 48.0** | 0x10 帧 battery 字段 | ______ | 接分压电阻 ADC 后按实际分压比换算 | 🔴 占位,必须改 |
| Fw-6 | `SLEW_ACC` | retrofit.c:15 区 | **0.2 m/s²** | AUTO 起步/纠偏斜坡 | ______ | 台架阶跃切 AUTO,0.1/0.2/0.4 三档试;验收:切换瞬间轮速无可见跳变、纠偏超调 ≤20% | 🔴 待整定 |
| Fw-7 | `LINK_TIMEOUT_MS` | retrofit.c:14 | **500** | PC 链路超时→急停 | ______ | 台架拔线用录像数帧验证;现场 WiFi 实测抖动大再放宽 | 🟡 原则上不改 |
| Fw-8 | SBUS 通道→四轮速度映射 | main.c/path_plan.c(原车逻辑) | **未登记** | MANUAL 遥控与 AUTO 指令的量纲对齐基准 | ______ | B6③:固件加打印或看 led.c switch_ch,列通道-速度表 | 🔴 缺表,影响 C4 |
| Fw-9 | 轮序约定 | 集成说明.md | **左前/左后=vl,右前/右后=vr**(veloc[0..3]) | 差速指令到四轮的分配 | ______ | 台架发 vL≠vR,观察转向方向;**与 P0 转向符号问题同场验证** | 🔴 待实测 |
| Fw-10 | 双 IWDG 并存 | ~~main.c:236(ALIENTEK 1s) + retrofit.c:129(1.6s)~~ | **✅ 已整改(09-04 ea5106a):撤销 retrofit 重复 IWDG,保留 main.c 1s 一套(主循环喂;retrofit/TIM6 锁死停喂同样触发复位)** | — | — | 台架确认 `delay_ms(1000)` 等长阻塞不误触发 | ✅ 已修,待台架验证 |
| Fw-11 | AUTO 未接管转向 | — | retrofit 门控只注入 veloc[](轮速),angle[](转向角)仍由 path_plan 从 SBUS 每周期计算并下发 | **AUTO 期间转向跟随遥控摇杆——无人作业时安全隐患** | — | 修复:AUTO 分支强制 angle[0..3]=直行角(或 PC 航向指令),MANUAL 不变 | 🔴 固件待改 → **✅ 09-14 已编码已编译(H2.2,main.c:518-519 清 angle + 四处 send_angle 仲裁 Switch_direction),待台架** |
| Fw-12 | 转向零位/跑偏 | — | wheel_Angle_correct 上电一次性采样标定(假设上电时车轮为正);开环无轮角反馈 | **遥控走直线跑偏的可能根因**:①上电时车轮未摆正→误差烙进零位;②传感器链未工作 correct=0(代码注释自认第二辆车未装);③四轮修正符号不对称放大误差;④伺服一圈脉冲/传动比与实物不符 | — | 排查:上电前人工摆正车轮对比;遥控置中看打印四角;实测各轮偏角单独修 correct;核对伺服脉冲参数 | 🔴 台架标定项 |
| Fw-13 | **限位开关"哪一端算触发"的口径**（文档与固件相反） | retrofit.c:279-282（`stepper_update` 闭锁）＋ retrofit.c:213-216（`read_limits` 上报） | **低电平 = 已撞限位**：代码注释原文 "active-low switches: 0 = hit"，`read_limits` 也是 `!bit` 才置位 ⇒ 与它相符的只有"静止时开路、撞到才接地"的**常开**开关 | 三处文档写的都是**常闭**：接线图_v1:35「限位开关×3(常闭,接地)」、接线图_v1:157「常闭型」、缺口清单:160「开关接地、内部上拉、闭合=低」＋「常闭型优先（断线即触发）」 | **后果不接件也能复算**：装常闭 ⇒ 静止即闭合＝低 ⇒ 固件判"已撞"，`lim_left==0 且 err>0` 与 `lim_right==0 且 err<0` 同时把 err 清零 ⇒ **滑台两个方向都动不了**；而"断线即触发"这个安全目的恰好相反——断线＝开路＝内部上拉＝高 ⇒ 固件判"没撞" = **失效静默**。**09-28 台架旁证（滑台根本没接线）**：`limits=0x06` 里 PD15 读到 1（悬空读到上拉，符合预期），PD10/PD11 却读到 0 ⇒ 这两个网络上挂着外部驱动或下拉，与接线图_v1:85 记的"PD15/10/11 走 U5 输入缓冲，V3.3 已贴片"一致；**U5 型号与 T4/T10 有无跳线帽待照片/原理图定性，本行不下结论** | 定口径之后：开关接上对应端子，分别量"静止"和"压到"两种状态下该脚电平，再对照固件判读；`read_limits` 上报的三位也应跟着一起验 | 🔴 **口径冲突待作者定**（二选一：固件改成"高＝触发"以配常闭＋断线即触发；或三处文档改常开并放弃"断线即触发"这个卖点）。属门 F，**09-28 不动固件**，先只登记 |

## 2. PC 侧参数(pc/*.py, tools/*.py)

| # | 参数 | 位置 | 现值 | 含义 | 实车实测值 | 测法 | 状态 |
|---|---|---|---|---|---|---|---|
| Pc-1 | `px_to_meters` 比例 | pc/perception.py(IPM_SCALE) | **0.0015 m/px(占位)** | 像素→地面米换算 | ______ | 样机机位外参重标定(C3；09-21 起不再叫"低机位"，相机离地 100 cm 见 Hw-20):田面 40/50cm 标记点,3 点投影误差 ≤2cm;**换 pc/calib_ipm.py 产出后替换硬编码**，产物必须带 source_image/points_source/vehicle_profile/calib_date/n_points/pixel_space 六项来源字段，否则 pc/ipm_io.py 会拒 | 🔴 占位 |
| Pc-2 | `ESTOP_LAT_LIMIT` | pc/main.py:31 | **0.05 m** | 横向偏差软急停阈值 | ______ | 实车行的实际行距/允许偏差定;与单墙模式 ±200px 注入偏移(≈0.3m)联合评估 | 🟡 待实车定 |
| Pc-3 | `v_nominal` / `v_max` | pc/control.py | **0.14 / 0.2 m/s** | 巡航/限速 | ______ | C4:发 vL=vR=0.14 实测车速应为 0.5km/h(秒表量 10m),不符改 Fw-8 量纲而不是这里 | 🟡 与 C4 联动 |
| Pc-4 | PID 参数(kp/ki/kd) | pc/control.py | **0.8 / 0.05 / 0.1** | 中间刀滑轨 | ______ | 台架阶跃响应整定 | 🟡 待整定 |
| Pc-5 | 单墙模式行距偏移 | tools/morph_process.py | **±200px 硬编码** | 单墙时中心线补偿 | ______ | 按实际行距+机位换算,并入 Pc-1 标定 | 🔴 占位 |
| Pc-7 | **checkpoint 身份** | `model_data/weights/best_model.pth` 与只读仓 `chucao_prj/model_data/0.7428m/best_model.pth` | 两份都是 21,158,562 B，但 md5 前 8 位不同（`32da179c` vs `cdd22733`） | **大小相同、内容不同 → 不是同一个 checkpoint**，不能互相替代引用。09-21 起 `tools/pre_annotate.py` 每次运行打印所用权重的 md5/mtime/大小与 state_dict 容器形态 | ______ | 按 `train_metric_log.csv` 反查各权重对应的 epoch；正式训练/预标注前冻结"划分 + checkpoint + epoch + 成组指标"（v1.0 P9 同源要求） | 🔴 待冻结 |
| Pc-6 | IPM_SRC 梯形/尺度 | pc/perception.py | **硬编码(旧机位)** | 逆透视映射 | ______ | C3 重标定,目标:改读 pc/calib_ipm.py 的 ipm_params.json | 🔴 占位 |

## 3. 硬件结构差异(实车 ≠ 固件假设)

| # | 项 | 固件/设计假设 | 实车情况 | 记录 | 状态 |
|---|---|---|---|---|---|
| Hw-1 | PC6/PC7 串口占用 | USART6 纯 TTL 直连树莓派 | 板上 PC6/PC7 兼接 485 收发器 U7(引 T6),TTL 引出点待确认 | 接线图_v1 §1 | 🟡 **09-23 以 `大板.pdf` p0 的厂商装配注为准重写本行**。⚠️ **撤回**此前"U7 那路选型 0R 是 R23(TTL)/R13(485)、两颗都贴着"的说法——那是**照片推断**被我照抄的，位号归属错了：R13/R14/R23/R24 属 **U8 那一路**，与 USART6 无关。厂商原文（p0，U7 块）：**「485: R15、R16默认焊接」+「R25、R26默认不焊接」**；另有「R13、R14默认不焊接」「R23、R24默认焊接」「U8及相关器件默认不焊接」属 U8 块（⇒ 照片上"U8 疑似空焊"是**设计如此**，不是版本差异，接线图 §5A#1/#2 那句要改）。⇒ U7 这块是**两条并联支路**：R15/R16 走 485 芯片（默认通），R25/R26 是 **TTL 直通 T6**（默认断）。**09-23 作者焊上 R25/R26 = 走对了路**；但 **R15/R16 仍在 ⇒ U7 的 RO 还挂在 PC7 网络上**，并联一条新路不等于旁路旧器件。**09-23 作者补测实板：R15、R16 并未焊接**（厂商注写"默认焊接"，按铁律以实板为准）⇒ **撤回"拆 R15/R16"那条待办**：485 芯片的 TTL 侧本来就断着，焊上 R25/R26 之后正是厂商预留的 TTL 直通配置。**新的待证点**：作者把 X5 的 TX/RX 接在 T6 的 **A_4、B_4** 上，而这两个 pad 也是 U7 的 A/B 输出落点——若 U7 在位带电、其 DI 因 R15 开路而悬空，自动换向器件**可能仍在驱动 A/B**。三条量表定性（见接线图 §7）：① 断电量 A_4–B_4 间电阻（120Ω 端接是否挂着）；② 带电、X5 不接，量 A_4、B_4 对 GND 静态电压；③ 1k 把 A_4 拉向 GND，看拉不拉得动（拉不动=有驱动在抢）。**端接/TVS 本身对 115200 影响很小**：120Ω 跨在 A-B 之间，而 B 侧现在是 X5 的高阻输入，不构成直流负载；SMF6.0CA 在 3.3V 下不导通，只剩结电容。⇒ 要排除的只有"U7 还在驱动"这一条。**最终判据不变：双向都通 + `rx_bad` 长期为 0**（反向 = PC 发指令后大板 `mode` 跟着变）。 **搬运提醒：电阻跟着大板走，真实车的 T6/485 装配状态未知，届时"T6 可用"不得继承，按同一判据重测。** |
| Hw-2 | SL1 覆盖范围 | 急停断动力 | SL1 只切 MOTOR_1 的 24V,MOTOR_2 不断 | 接线图_v1 §6 | 🔴 待评估影响 |
| Hw-3 | 刀继电器极性 | 高电平=提刀 | 待实车核对继电器模块常开/常闭 | 接线图_v1 §2 | 🔴 待确认 |
| Hw-4 | PB5/PB6/PB7 引出 | 假设有引出点 | 原理图未见,可能需飞线 | 接线图_v1 §3 | 🔴 待确认 |
| Hw-5 | 车轮/轮距/机位高度 | PC 感知按 0.9m 机位 | 实车支架实际高度/轮距用于 IPM 与 c_per_pulse | C3 标定时登记 | 🔴 待实测 |
| Hw-6 | 车端网关选型 | 原设计树莓派 4B(vehicle/ 代码按 Pi 写) | **✅ RDK X5 已到货并验机四项全过(09-10,见 docs/X5验机与接入执行清单.md)**:OS 3.5.0,SSH sunrise,eth0 静态 192.168.127.10,40pin UART1=Pin8/10→/dev/ttyS1(3.3V);视频链定型 TCP multipart MJPEG(105ms@30fps 网线/104-225ms 网桥);config.yaml 适配已入主线 | X5清单+台账本行 | 🟢 已明(上车供电/接线上车日做) |
| Hw-7 | 步进驱动器 | 固件按通用 PUL/DIR/ENA | **09-05 实车确认:中间刀左右微调不是步进!是低压直流伺服(60法兰 400W 48V 3000RPM 1.27Nm,速度/位置模式,脉冲方向/485/CANopen,单圈/多圈绝对值编码器,¥599,链接4)**。伺服在位置模式下接受 PUL/DIR,固件 TIM4 接口兼容,但:①`STEPPER_STEPS_PER_MM` 按伺服电子齿轮重标(Fw-1);②限位开关可保留作保险,伺服自身有编码器和原点;③转向电机与此同型——**同一型号电机既做转向也做中间刀微调** | 本行 | 🔴 固件待改 |
| Hw-8 | 视觉相机 | 原设计 CSI 相机接 RDK MIPI | **✅ 09-10 实物核实:手头相机 = LRCP imx291(0c45:ae11,UVC 1.0,MJPG 1080p30)**——与台账原记 DCXW20030(DCXW 系选型参考)不同型,imx291 底、夜视好,满足需求;已实测推流 30fps。⚠️ **USB 线材接触不良两次实测掉设备(dmesg error -71),上车必须换优质 USB3.0 短线直插蓝口(并入 F6)** | X5清单§6.5 | 🟢 已明(换线待办) |
| Hw-9 | 除草刀升降执行 | 固件假设 3 路刀继电器(梁1-3 各一,高=提刀) | **✅ 09-05 确认:3 根电推杆(BST-YF-L,48V,200mm,10mm/s,3000N)=3 行刀升降(被动进土),已在车上,由外接继电器板控制(现有,非新购)**。固件接入方式待实物确认:①外接继电器板若为电平触发输入 → 我们 6 路输出(T5 判活+U3→DR25 备用脚)并联/替换其输入;②若绑死遥控器/原控制器 → 需切换电路。**拍照确认:继电器板路数(双向换向需 6 路或板内已有换向逻辑)、输入触发极性、现有触发源**;固件伸/缩互锁+ESTOP 强制全提不变;10mm/s 全程 20s 提刀指标重评 | 接线图_v1 §4 | 🟡 待实物确认输入方式 |
| Hw-9a | T5 三路继电器用途 | 固件假设=刀继电器 | **✅ 09-05 修订:V3.3 完整板上 U6 已贴片(此前"U6 空焊佐证原车未用"的推断作废)——T5 这条输出链路是通的,后端是否接了负载仍需 B6 跟线确认**;电推杆经现有外接继电器板控制,接入方式待该板照片 | 接线图_v1 §4 | 🟡 待照片 |
| Hw-10 | 行走电机 | 固件假设 TIM1 4 路 PWM 直驱电机控制器 | **✅ 09-05 用户确认:实车行走电机控制就是固件里的同款(TIM1 PWM 直驱成立)**,48V1000W 中置套件与原车控制器同协议;轮速反馈仍按 DR25 霍尔→LM393 走(接线图 §2 不变) | 接线图_v1 §2 | 🟢 解除,无需改 |
| Hw-11 | 转向反馈 | 固件/原车:轮角电位计(经 U17,空焊)或 485 编码器(USART2) | **✅ 09-05 查固件:转向伺服走 UART4 19200 Modbus-RTU(uart4.c,经 485 第 3 路引出)**——motor_EN(0x0001)/motor_speed(速度模式,寄存器 0x0002)/send_angle(绝对位置,寄存器 0x0016,int32 脉冲,一圈 32768);丝杆传动(150mm 弧长/导程 5mm/减速比 5),transmission_ratio_steer 传动比参数。**到货后对照新伺服驱动器寄存器表,一致则零改动**;反馈由伺服内部闭环,原车轮角采样链(U17/485)退役 | uart4.c | 🟡 待寄存器表核对 |
| Hw-12 | 中间刀左右微调 | 固件有 tool_offset/PID/TIM4 链路 | **✅ 09-05 用户更正:车上已装有同型伺服+丝杆滑台,只是未接线**——接法二选一:①脉冲方向模式(固件 TIM4 原路径复用,重标电子齿轮);②**Modbus-RTU 挂 485 总线与转向同线不同址(推荐,复用 uart4.c,自带闭环)** | 本行 | 🟡 待接线+寄存器核对 |
| Hw-13 | 转向电机 | ~~链接4 伺服套装=新购~~ | **✅ 09-05 用户澄清:转向电机在车上、已接线、遥控可控(MANUAL 正常);四个购买链接是车上既有部件的参考,非新购**。转向伺服与固件 uart4.c 协议天然一致(原车配套)——**Modbus 寄存器核对只剩中间刀滑台那台(Hw-12),且若同厂同型号也大概率零改动**。遗留固件问题:Fw-11(AUTO 未接管转向) | — | 🟢 已明 |
| Hw-14 | 整车几何尺寸 | 用户所指"参数出入"=车长/宽/高等 | **待实测登记:车长/车宽/车高/轴距/轮距/离地间隙/刀架位置/相机安装高度与俯角**——用于 IPM 标定(Pc-1)、试验记录(M4)、论文样机参数表;测量方法:卷尺逐项,拍照留档 | C3 标定时一并 | 🔴 待实测 |
| Hw-15 | **RDK X5 供电** | 文档曾三度出错(12V会烧板→多档PD→必须PD)，2026-09-12 以手册定案 | **✅ 设备手册原文(权威)**:供电口 = **USB Type-C 接口 1**;输入 = **5V/5A(25W)**;"需要使用支持 5V/5A 的电源适配器";上电绿灯=供电正常、3.1.0 后橙灯闪=系统正常。**推论**:电源须能输出 5V/≥5A,线材须过 5A;**实现方式手册未规定——固定 5V/≥5A 降压(首选,对应手册"5V/5A适配器"形态)或 PD 广播 5V/5A 源皆可**;避开只到 5V/3A(15W) 的源(满载会欠压重启)。车厢供电:48V→〔保险丝2A+TVS〕→ 48→5V/6A → X5 | docs/车上供电与接线清单.md；来源=用户查手册原文，定案人=用户+ZCode | 🟢 已明 |
| Hw-16 | **车端/PC 端网桥供电** | — | 车端网桥 9–13V 输入,**12V 合规**:48V →〔保险丝+TVS〕→ 48→12V/≥1.5A → 12V 圆口 → 网桥;PC 端网桥有市电用原砖、田头用 12V 便携源;笔记本网口只传数据不供电。**48V 侧总电流 ~0.8A(25W+12W),2A 保险丝够** | docs/车上供电与接线清单.md；来源=用户确认 | 🟢 已明 |
| Hw-17 | **SBUS 接收机帧格式与 flag 字节语义** | 标准 SBUS:25 字节,帧头 0x00,16 通道按 11 bit 打包,byte24 为标志位(**0=正常**,bit1=failsafe,bit2=frame lost) | **实车固件解析与标准不符**(telecontrol.c:142-161):帧头校验 `0x0F`、16 通道按 **16 bit 未打包**逐对读取、byte[33] 当标志、byte[34] 当 XOR。`flag_sbus = byte[33]` 后原码假定 **>0 才是正常**(与 SBUS 规范相反);且 `LOCK_FLAG` 全工程**只写不读**(死代码),该假定从未被运行验证过。**因此 09-14 的失联保护明确不用 flag 字节做判据,只用帧头+XOR**——若按相反极性去门控心跳,可能直接封死遥控驱动。待办:台架打印 byte[33] 在"正常/拔接收机/遥控器失联"三态下的实际值,再决定是否启用 failsafe 位 | uart4/telecontrol.c:142-175 | 🔴 待台架实测(禁止推测覆盖) |
| Hw-18 | **刀数与布置** | 文档曾按"3 侧刀 + 1 中间刀"(4 把)理解 | **✅ 2026-09-15 汇报人口述确认:2 把侧刀 + 1 把中间刀,共 3 把,对应 3 条草带**。左右侧刀固定在刀梁上、只管进土不管横移;**只有中间刀装在滑台上可横向移动**,故"主动对行"仅发生在中间刀;3 根电推杆分别管三个刀梁升降(与 `retrofit.c` 的 `lift_bits` bit0..2=三梁一致、ch02:105"左右刀梁固定"一致)。此前 qoder 在组会材料里写成"3 侧刀+1 中间刀"属数错,已改。**补 09-21:鸭掌铲刃宽 25 cm** → 与弹齿登记的 250 mm 五齿**幅宽对等**,ch05 组1"鸭掌铲 vs 弹齿"的对比条件不对等问题解决(M7 就此关闭)。**另:汇报人澄清"车宽"= 车正面从左到右的外廓宽度**(即 2.15 m / 3.25 m 是外廓,不是轮距) | 组会汇报_20260916/deck_order_map.md 第7页;本行 | 🟢 已明(现场确认) |
| Hw-19 | **行距与坡度** | ch02:14 与 ch05:8 登记"行距 30~60 cm、坡地 5~15°" | **✅ 2026-09-16 汇报人改 PPT 时现场确认为:行距 30~40 cm、坡地 0~15°**。按事实权威序以现场值为准 → **论文 ch02:14/ch05:8 两处待改**;注意连带影响:行距上限从 60 收到 40 cm,则"轮距与刀间距机械可调"的调节范围、以及 30~40 cm 下的通过性余量需重算(与 Hw-14 整车尺寸实测一并做) | 组会汇报_20260916/paper_analysis.json f_agron | 🟡 论文待改 + 通过性余量待重算 |
| Hw-20 | **样机底盘实尺（两台车）** | `ch02:14` 登记"整机宽度不大于 60 cm"；`计划:11` 与 deck 第 7 页写"跨 4 行清 3 带" | **✅ 2026-09-21 汇报人现场确认（最高权威）。本项含两台车，论文必须点名用哪台：**<br>· **真实除草车**：车宽 **2.15 m**、车长 162 cm、除 **3 行**；**现在在地里**<br>· **上代除草车**：车宽 **3.25 m**、车长 162 cm、除 **6 行**；两车差异仅车宽 + 去掉几个刀头（6 行→3 行）；**当前用它调固件/算法/通信**；**上代车上只有一个除草刀推杆带丝杠左右微调电机**<br>· 共同：相机镜头离地 **100 cm**、轮胎 **Ø60 cm**、**轮距 = 车宽 − 24 cm**（左右各减 12）；刀中心到车纵向中心线**不用登记**（可物理调节）<br>**可复算的几何事实（不是结论）**：真实车轮距 191 cm、上代车 301 cm；若行距取 35 cm，191÷35 = **5.46 个行距**。**⚠️ 09-21 复审后撤回原推论**：本行此前写"→ 轮下压过 4~5 行作物"，这个箭头不成立。"两轮之间跨过几行"与"轮胎接地条带压住作物行"是两件事——反例：行距 38.2 cm 时 191 cm 恰为 5 个行距，作物行中心在 0、±38.2、±76.4、±114.6，两轮中心 ±95.5 cm 正好落在 76.4 与 114.6 之间的行间。**判断压不压苗还缺四项实测**：轮迹相对行线的横向偏差、胎宽、作物保护带宽度、行驶跟踪误差；机架是否碰冠层另需机架高度。`tools/geometry_check.py` 已同步改为只报"几个行距 / 残差 / 是否可能对得上行"，不再输出压苗结论（反例与判据已进 `tests/test_geometry_check.py`）。<br>**打中的旧文档**：① `ch02:14` 的 ≤60 cm **错 3.6~5.4 倍**，而它正是第 2 章"通过性"的设计约束；② `ch02:23`"低机位前视单目相机"与 100 cm 矛盾（轮心才离地 30 cm），C3"低机位 IPM 重标定"与 deck 相应措辞同批要改；③ 相机正下方地面分辨率 ≈1.27 mm/px（H/f=1000/790），前视远处按俯角急剧变粗。<br>**未决（阻塞论文与门 N）**：论文样机是哪台？真实车有几把刀、是否保留丝杠微调？"3 行"是 3 条作物行还是 3 条草带（Hw-18 的 2 侧刀+1 中间刀 ↔ 3 带 ↔ 跨 4 行，口径需对齐）<br>**✅ 样机身份已定（09-21 汇报人）：论文样机 = 真实除草车（2.15 m，3 行）**；上代车（3.25 m）定位为**调试平台**，不作为样机写入第 2 章尺寸。汇报人补充"两台车没区别，只是车宽不一样"——该说法**只对一半，必须分开记**：<br>· **可复用（与车宽无关，但"复用＝可搬过去再确认"，不等于搬完就不用测）**：串口协议与帧格式、固件模式机与安全门控的**代码**、SBUS 失联保护与 STATUS 新鲜度的**实现**、通信链路的软件模块、控制律结构与增益形式、预标注/分割模型本身，以及它们在上代车上的**调试记录**。<br>· **搬过去仍须逐台确认**（09-21 复审订正）：实测时延（数值不跨车继承，每台车重新测）、接线与执行方向、SBUS 失联在这台车上是否真的停车、急停实际切断哪些电源、供电、现场链路。协议解析测试通过 ≠"这台车确实停下来了"；两者是不同层的证据，不得互相顶替。<br>· **不可迁移**（车宽直接决定）：轮迹与作物行的相对位置、行墙视野布局与有效双墙占比、中间刀横移所需行程、以及一切"跨几行清几带"的结论。<br>· **待核验而非必然不同**：相机内参与 IPM。车更宽**不是**光学参数变化的充分原因——能否复用取决于相机、镜头、成像设置、安装姿态与坐标定义是否一致。当前两车的这些档案都不全，所以按"REAL 重新标定"执行是**合理的工程选择**，但要写成核验要求，不要写成物理定律。<br>· 推论：凡在第 4/5 章报横向指标（对行偏差、伤苗率），**必须注明采集自哪台车**；用 3.25 m 平台的横向数据为 2.15 m 样机背书，是答辩可直接击穿的空档。 | 本行 + v1.0 §4.1 门 N | 🟡 样机已定；**"必然压苗"已撤回（09-21 复审），改为待实测**：轮迹与行线的横向偏差、胎宽、保护带、跟踪误差四项都要 N1 田块横断面照片 + M3/M7–M15 量出来才能判；真实车刀头数现场核对（M13，5 秒钟的事）仍待 |
| Hw-21 | **控制栈装车位置** | 文档默认"改造控制栈已装在大车上" | **✅ 2026-09-21 汇报人确认：控制栈（大板 + RDK X5 + 相机 + 网桥）尚未装到任何车上**。计划：先装**上代车（3.25 m）**试验，验证"能不能用电脑控制"、看有什么问题；没问题再搬到**真实车（2.15 m，样机）**。关键约束：**真实车现在在地里，不好运** → 搬运是**一次性事件**，不能反复拆装试错。<br>**因此的执行含义（详见 v1.0 §4.2）**：S1 装车与链路（B1/B2/SBUS 两子情形）、S2 平地空跑冒烟 都在上代车上做完（这些**可跨车迁移**）；S3 搬运日必须**先断电逐项核对接线**（48V 极性、共地、保险丝、刀梁锁定、急停切断范围）再通电；S4 样机机位 IPM 标定、C1 采集、门 N 预实验只能在真实车 + 目标田块做（**不可跨车**）。<br>**诚实结论**：秋季"双保险"里能保的是图像与标定层；V2 自主沿行要 S3/S4 都成才有，若搬运失败则 V2 落到春季——此点须如实写进方案，不能到 4 月再解释 | v1.0 §4.2 | 🟡 计划已定，S1 未开始 |
| Hw-22 | **秋季物候（10 月中那块田的芍药地上部状态）** | 采集清单把秋季分"叶片完整期/半枯期/枯萎期"三档；分割模型用夏季**叶片完整期**数据训练 | **汇报人 2026-09-21 判断：10 月中叶片还基本完整** → 现有模型大概率仍能提出作物墙，秋季押 V2 自主沿行成立。<br>⚠️ **口径标注：这是对 10 月中的预测性判断，不是已复核的现场事实**。感知提的是"作物前景→左右垄墙"，若届时实际已进入半枯/枯萎，前景像素消失会让 V1/V2 同时失效，与装车进度无关。<br>**廉价复核手段（v1.0 §4.2 的 S0）**：人带相机去那块地拍 50 张（不必搬车），用现有权重跑 `tools/pre_annotate.py` 看前景占比分布；前景≈0 即触发 §8 退路（改验证"垄沟/裸土通道提线"可行性，C1 图像照采） | v1.0 §4.2 / §8 | 🟡 判断已记，待 S0 现场复核 |
| Hw-23 | **上代车行走执行方向 + 固件几何常数（09-23 现场首测）** | `main.c:27-30`：`B=1530 / L=2550`、横向档 `B_Horizontal=2780 / L_Horizontal=1390` | **① 作者 09-23 现场实测（09-21 镜像已烧入、遥控 MANUAL 档）：横向与纵向行驶时，前、后行走电机转向相反；同日二次实测细化为：两档均为"推前进时前轮向后、后轮向前"，与模式无关。**<br>**② 几何常数与 Hw-20 实测均不符**：上代车轮距 3010 mm、车长 1620 mm，固件四个数没有一个对得上 → "没改"成立。<br>**③ 但②不是①的原因（代码判读，09-23）**：B/L 只进 `angle_limit=atan(2*L/B)` 一类**转向角限幅**（`path_plan.c:251/256/269/274`），缩放角度、不产生轮速符号；横向前后相反来自 `path_plan.c:548-555` 的**带负号置换**（`veloc[0]=-veloc[1]` 等四句），该处注释自认"注意不同车型、谁和谁一致"——即原设计对**原车接线/转向安装方向**的补偿。**⚠️ 09-23 二次实测后修正归因**：我首测时提的"横向标志位未回位"（`path_plan.c:221-224` 清除分支被 `control_flag[4]` 门控）**不成立**——该假设预测两档行为不同，实测两档签名完全相同（均为前轴反相）。当前签名指向三类候选，按排查代价递增：**a) 前轴电机控制器的方向设置（拨码/跳线/参数，最便宜，先查）**；b) 前轴动力线极性接反；c) 大板 TIM8 通道→轴的映射与这台车不同。判据：推后退是否整体镜像翻转（是=符号问题，否=通道错配）；控制器铭牌与拨码照片。<br>**⑤ 09-23 代码侧排除（对只读原仓 `chucao_prj/hardware_ref` 逐字节 diff）**：`path_plan.c` 与厂商源码 **0 行差异**；`car_control.c` 仅多一个 AUTO 早退块（手动档落回原符号分支）；`main.c` 手动档唯一差异是"SBUS 失联清零门"——**该门若生效轮子应不动而非反转，实测轮子在转，故未生效**。⇒ 本镜像手动档行为与厂商镜像等价，"烧录前正常/烧录后反相"不能归因于代码，除非两次之间接线状态变过；**而 09-23 正是装车日（S1，拔插过连接器）**。候选收敛为：今日拔插导致的前轴信号/动力插头反接、DR25 J1/J2 接错、或前轴控制器被换/拨码被碰。<br>**⑥ 09-23 作者指示实施补偿（改代码+改本表+重编译，三步齐）**：`car_control.c` 新增 `FRONT_AXLE_DIR_SWAP 1`，在 Out_Pwm 四个分支里把前轴两轮方向引脚（`Roll_LF_Dr/Roll_RF_Dr`）极性取反——方向由方向引脚带（左右两侧极性本就镜像），**翻 PWM 数值会落进"无分支匹配"的空档使车保持上一条命令，故不翻数值**。`UV4 -r` = **0 Error / 60 Warning / Code=44848**（与改前同尺寸：仅常量变化，指令数不变；`retrofit_sbus_ok` 仍 @0x0800886b），hex/map 09-23 13:36 再生，hex 仍 130,670 B ⇒ **认版加一条：mtime 必须是 09-23 13:36**。回滚 = 宏置 0 重编译。<br>**待吊轮验证（🟡）**：推前进四轮同向 = 补偿正确；若轮子抖/啸叫/转速飞 = 霍尔在电机轴侧、速度环成正反馈，**停测**，第二版连 pid setpoint 与反馈一起翻。验证通过前，本行状态不算关闭，门 N 的 AUTO 仍禁。<br>**⑦ 09-23 同日：补偿假设被新观察动摇，宏已改回 0 作测量基线**。作者再测报为**单轮（左前）反相**，并能把它与横向档的右前对上号——这与"整轴镜像"不相容（整轴镜像下应两前轮同反）。⇒ ⑥ 那次补偿**在假设不成立的前提下写就，不能留在测量链路里**，`FRONT_AXLE_DIR_SWAP` 已置 0 并重编译（0 Error/60 Warning/Code=44848，hex 09-23 15:31，仍 130,670 B ⇒ **认版 mtime 更新为 15:31**）。**下一步只测表不改码**：四轮贴物理标签，在厂商极性下记三列（纵向+前进开关、纵向+后退开关、横向档），我按表写**逐轮符号向量**（可能就是 LF 一个轮），不再按轴猜。<br>**⑧ 后退模式的事实（作者问"是不是没有后退"）**：有，但**不在油门杆上**——`path_plan.c:178-183` 油门带 `ch[4]>=1600` 算出的速度被夹在 `[0, veloc_actual]`，恒非负；前进/后退由 `sbus_channel[3]` 开关选（<1500 前进 / >1500 后退，`:160-174`，写 `control_flag[1]`），且 `:334` 在切换方向时强制零速过渡。**往回拉油门不倒车是设计如此，不是故障。**<br>**④ 准入含义**：`Out_Pwm`（`car_control.c:90-135`）的符号分支只有"全同向/全反向/左右相反"三档，**没有"前后相反"**——真出现前后相反时 TIM8 的 CCR 不更新，车保持上一条命令；而 AUTO 注入走同一条 `veloc[]`（`car_control.c:85-86`）⇒ **执行方向未确认前门 N 的 AUTO 不得上**。 | 本行 + path_plan.c / car_control.c | 🔴 待确认（09-23 二次实测后判据更新）：吊轮推前进/推后退各记四轮转向（镜像=符号问题，非镜像=通道错配）；拍前轴电机控制器铭牌与方向拨码。**首测的"四组 a/b/c/d"判据已被取代**（它服务于已降级的标志位假设）。**改 B/L 不会让①消失，别拿它当修法**；若最终确认要补偿，极性应进**车辆档案字段**（E3 ③ 的 PREV/REAL 档案天然该带 `轴符号` 一项），不要硬编码进 `Out_Pwm`，否则搬到样机又错一遍；正确几何值以 Hw-20 为准（上代轮距 3010 / 车长 1620），改参数走"改代码+改本表+重编译"三步 |
| Hw-24 | **`car_control.c` 整个文件是死代码；真正的行走方向在哪** | 09-04 起我们的 AUTO 注入与"门控"都往 `car_control.c:Out_Pwm()` 里加，接线图/retrofit.c:262 注释也写着"AUTO 走 Out_Pwm 路径" | **09-24 实测：`Out_Pwm()` 全工程无任何调用点，linker 把 `car_control.o` 整个丢弃（`OBJ/PWM.map` 里既无 Out_Pwm 也无该 object）**。**真实链路**：`main.c:552-561` 调 `pwm.c:188 pwm_veloc(adress, veloc[i])` → 函数内按**速度符号**调 `led.c:398 replay_switch(ch,0/1)`（PE 口继电器换向）→ 幅值写 **TIM1** CCR。⇒ `car_control.h` 里那套 `Roll_*_Dr / Roll_*_BK = PGout(1..8)`属于上一代硬件（TIM8 + G 口），本车不走它；PG3~PG8 在活镜像里由 `led.h:60-65` 的 `MP3_IO_*` 独占。**我今早提的"MP3 抢刹车线"假设作废**——那些刹车脚在死代码里，本车方向/刹车根本不走 G 口。**已做**：左后轮方向翻转改在真实调用点 `main.c` 的 `pwm_veloc(2, -veloc[2])`，宏 `REAR_LEFT_DIR_SWAP=1`，回滚置 0。证据：Code 44848→**44864**（前两次改死文件时字节数一字不变，这本身就是"补丁没进镜像"的可复核信号）。**遗留债务**：`car_control.c/.h` 应删除或显著标注为"上一代硬件遗留，勿在此改"，否则下次还会有人往那儿打补丁（包括我们自己）。 | 本行 + main.c / pwm.c / led.c / OBJ/PWM.map | 🟡 补丁已进镜像，**待吊轮验证左后轮是否转正** |
| Hw-25 | **行走轮数与"正面"定义（影响驱动模型与 AUTO 方向）** | 文档与固件都按"4×行走电机四轮驱动"处理（`car_control`/retrofit 的 TIM3 四轮霍尔捕获、v1.0 §4.1 差速模型） | **09-28 作者现场：有一个轮没有行走电机，是从动轮** ⇒ 实际只有 3 个驱动轮。⚠️ **同一天的口述改过一次**：先说"右后"，随后更正为**左后**——按铁律以最新现场为准，但这里把"改过口"留着，因为下面每一条推论都依赖"是哪个轮"，不能假装一次说定。**✅ 09-28 已确认：左后**（作者手调 `main.c:19` 并加注"本车从动无行走电机"），改过口关闭。连带三件事要重算：① retrofit 的四轮轮速平均（`retrofit_wheel_speed()` 把四个通道一起平均）里有一个通道永远读不到脉冲，平均出来的车速系统性偏低，`c_per_pulse` 标定也按四轮假设；② 差速/Ackermann 模型对"三轮驱动一轮从动"是否成立，需要确认从动轮会不会被拖着空转；③ 门 N 空跑时从动轮不打滑的前提要写进试验记录。**"正面"的定义（作者 09-28 明确）**：挂除草刀那一侧 = 正面，**相机装在刀上方、镜头朝前** ⇒ 车必须朝刀侧行驶，否则 AUTO 会倒着离开它正在看的方向。这条以前没写在任何文档里，而它是感知—控制对齐的前提。**已据此把方向补偿做成逐轮四个开关** （`main.c:17-20` `DIR_SWAP_LF/RF/LR/RR`，装在真实调用点 `main.c:564-573` 的 `pwm_veloc()` 上——**出口处翻转，所以纵向/横向/四轮转向/原地转全部一起变**，这正是接线极性补偿该有的作用域；若某轮"纵向对、横向错"，那就不是极性问题，而是 `path_plan.c:548-555` 的轮序置换对本车不成立，改法完全不同。**车上实际生效值（作者手调并保存，已进仓库）**：`LF=1、RF=0、LR=1、RR=0`⇒ 最终**只有左前一个轮需要翻**；中间那版"左前+右前都反/两反一正"的假设作废（LR=1 落在从动轮上，无实际意义）。当前 LF=1、RF=1、LR=0、RR=0，Code 44848→**44872**）。**验收标准不是"轮子顺眼"，是"车朝相机/刀侧走"**。 | 本行 + main.c:17-20,564-573 | 🟡 开关已进镜像，**待 Download 后验证整车朝刀侧行驶**；三轮驱动的轮速平均问题待处理 |
| Hw-26 | **大板 MCU 每 2.95 秒复位一次（09-28 台架实测，阻断门 N）** | 文档与所有既有判定都默认"板子一直在跑，只是模式不对"；`retrofit.c` 的 20Hz STATUS 就是按"常驻心跳"设计的 | **09-28 现场数据（前代车、车上电池、X5 独立 48→5V Buck、无相机）**：STATUS 帧流呈 **59 帧发完→断流→约 2.5 秒后从 seq=49 再起** 的方波，`tools/bench_status.py` 各轮起点 5.06/8.01/10.96/13.92/16.87/19.82 s，**周期恒定 2.95 s（最大偏差 0.01 s）**；小结 = 行数 111 / 好帧 111 / **坏帧 0** / 乱序 305 / **重启重同步 6**，证据 `results/bench_20260928_1436/bench_log.csv`。**判"MCU 在重启"是算术不是猜测**：`retrofit.c:28` 的 `tx_seq` 是 `static uint16_t`、全文件只有 `:233` 一处自增、无复位点 ⇒ 线上序号不可能自己回到 49；而"每轮第一个被打印的序号恒为 49"正是 `pc/status_rx.py:22 RESYNC_RUN=50` 的签名（重启后第 50 个被拒帧被放行），2.5 秒空窗 = 49 帧 × 50 ms。**判"不是看门狗"也是算术**：`main.c:251` 是 `IWDG_Init(4,500)`，PRER=4→64 分频、RLR=500，LSI 32 kHz ⇒ 超时约 1 s；若是"跑飞后狗咬"，帧流会在复位前约 1 s 就停（末帧应停在 seq≈39 而不是 58），周期会 ≥3.9 s，且每轮打印起点会逐轮漂移而不是恒为 49。**`stm32f4xx_it.c:63 HardFault_Handler` 是 `while(1)` ⇒ 故障也表现为狗咬，同样被这条否掉**。**已反查、没有软件复位这条路**：`NVIC_SystemReset` 全工程只有 `core_cm4.h:1638` 的定义、无调用点；除 IWDG 外无第二只狗在用（WWDG 只存在于头文件与启动文件向量表）。⇒ **当前最优解释是掉电级复位（BOR/POR 或 NRST 被拉），但"最优解释"不等于已核实，必须电量**。 | 本行 + `results/bench_20260928_1436/` + retrofit.c:28/233 + status_rx.py:22 + main.c:251 + Hw-27| 🔴 **阻断项，门 N 不得开始**。三条连带结论：① **安全**——每 3 秒重跑一次 `retrofit_init`，`:361` 上电即提刀，而 P0-7 已实测"上电首 500 ms 刀全落"，**此状态禁止挂刀、禁止带动力接线**；② **Hw-23/Hw-25 的"行走方向定案"作废待重做**——那四次方向观察是在这块 2.95 秒生命里做的，跨不过一个完整周期，复位修好后 `docs/四轮行走方向实测表_20260923.md` 整张重填再谈定案；③ 今天测到的 `mode` 恒 MANUAL 与前几天"烧录后车不动、像遥控没连上"**可能同源**，因此**场景 ④/④a/④b 在此状态下做出的结果全部无效**。**已排除：不是 X5 侧**——现场把 X5 Pin8→PC7（TX）与 Pin6（共地）都拔掉、只留 PC6→X5 RX，仍是 2.95 秒一轮 ⇒ Hw-1 的"U7 RO 对顶"不再是本现象的候选原因（Hw-1 本身仍未闭环，两件事别混）。**Hw-1 的"长期 rx_bad=0"判据在本现象修好前无法满足**：0 坏帧只在每轮 2.9 秒窗口内成立，而重启把窗口切成了一段一段。**取证时顺带确认的唯一好消息**：大板→X5→笔记本这一跳首次通到笔记本（已台架）。**下一步（按性价比，先电后码）**：a) 万用表直流档量大板 3.3V（或 5V 输入）对 GND，看是否每 2.95 秒掉一次；b) 看板上降压模块指示灯有无打嗝式闪；c) 换一台确定的电源/另一块电池复测周期变不变；d) 电量干净再动固件——`retrofit.c:226` 的 `battery_v` 是写死的 `48.0f`，**遥测永远看不见掉电**，要软件侧证据就得把 `RCC_CSR` 的 POR/PINRST/SFTFLT 复位标志读出来塞进 STATUS（需改固件+重编译，排在 a~c 之后） **09-28 现场回报 a/b 的目视部分已做，均为阴性：降压模块指示灯不闪、外部继电器不响**。⇒ 这两条各自收窄一点：指示灯不闪（若该 LED 取自输出侧）说明**输入侧/大轨大概率没塌，真掉也是掉在 MCU 自己那一路（3.3V LDO 之后）**；继电器不响说明复位**不是刀/继电器回路浪涌引起的**（本台架刀控本来就没接，符合预期，不能当作"已排除负载"）。**仍未做**：万用表量 3.3V（现场无表）、换电源复测、以及"断电—等 10 秒—上电，看是从一开始就 2.95 秒一轮还是先连续跑十几秒才进入循环"（这条不要仪器，能分开"启动即失效"与"热/累积型失效"）。**另需现场一张照片**：板子上现在除电源线与 PC6→X5 RX 之外还插/接着什么（ST-Link、旧 USB-TTL、SBUS 接收机及其供电、485 编码器线、转向伺服线）——**USB-TTL/编程器这类"另一台电脑的地"是共地环路和倒灌的常见来源，必须逐个退出而不是留着猜**。**读所引 CSV 之前先知道**：里面**没有 `gap_start`/`gap_end` 行**（kind 只有 `first` 1 行 + `frame` 110 行），这不是"当时没断流"，而是记录器自己的盲点——报文一直到达但全部被 `StatusReceiver` 判为旧序号拒收时，主循环走的是 `st is None` 分支，而 `check_gap()` 当时只在 `socket.timeout` 分支里调，于是这类"屏幕上看得见、CSV 里记不下"的空窗一行都不落。已修（静默判定改为每轮必做，并在 gap 行写明"这期间到达的 N 个报文全被拒收"，把"线上真没人发"与"发的人在重启"分开）+ 补 2 条回归测试。⇒ **本行那个 2.95 秒是从 CSV 的 `seq`/`t_rel` 两列算的，不是从 gap 行读的**：`seq=49` 落在 2.108 / 5.056 / 8.013 / 10.962 / 13.919 / 16.875 / 19.823 秒，相邻差值 2.948 ± 0.004 秒。 ✅ **09-28 现场定位：拔掉遥控接收机的供电之后 STATUS 连续、不再 2.95 秒一轮**（作者口述一次关联，**尚未复现确认因果**，判据与下一步见下一行 Hw-27）。这条把本行的读法收紧到预测的那一支：既然算术已经排除 IWDG 与软件复位，剩下能自持 2.95 秒周期的就只有电源侧（塌陷—恢复—再塌陷的弛张式重启），而接收机正挂在板上那一路供电上。|
| Hw-27 | **遥控接收机的取电方式把大板拉到掉电级复位（09-28 现场一次关联）** | 文档一直把接收机当无害传感器：`接线图_v1` 只写了 SBUS 信号链，接收机的**供电**没有出现在任何一项准入或量表里 | **09-28 现场：拔掉接收机供电 ⇒ Hw-26 的 2.95 秒循环消失、STATUS 连续**。反过来读更要紧：**此前所有靠遥控的观察（四轮行走方向、"烧录后车不动"、提刀动作）都是在一块每 3 秒冷启动一次的板子上做的** | 本行 + Hw-26 + `results/bench_20260928_1436/` | 🟡 **因果未确认，只有一次"拔了就好"**。两步缺一不可：① **复现**——把接收机供电插回去，看是不是又变 2.95 秒一轮（症状随 X 回来才叫因果，顺带排除"当时顺手动了别的线"）；② **分路**——只拔接收机的 **SBUS 信号线**、保留它的供电：照旧循环 ⇒ 供电侧（电流把轨拉塌或接收机内部短路）；连续 ⇒ 信号线那条路（反灌/共地环路）。两种改法完全不同，别把结论写死。**需要现场说清两件事**：接收机接在板上哪个口取电（5_A_V/5_B_V？舵机口？3.3V？）、接收机型号与通道数（它决定吸流）。**对准入的后果**：门 N 的自主运动要求 SBUS 新鲜（`retrofit.c:535-550` 门控 + H2 失联场景），**不能靠"索性拔掉接收机"来换取稳定**；真正的改法要么接收机改由独立 BEC/第二路 5V 供，要么换一路更大电流的 5V。这也是 AGENTS 那条"禁止从大板 5_A_V/5_B_V（各 1.5A）取电"第一次拿到现场数据支持——但受害的是板自己那一路而不是 X5，两件事别合成一条规则 |

## 4. 修改记录(改一笔记一笔,倒序)

| 日期 | 参数 | 旧值 → 新值 | 修改位置 | 验证方式 | 操作人 |
|---|---|---|---|---|---|
| 2026-09-21 | Hw-20 结论口径（**撤回，不是改数值**） | "轮距 191 cm ÷ 行距 35 cm = 跨 5.46 个行距 → 轮下压过 4~5 行作物" → **只保留前面的算术，撤掉箭头**。"两轮之间跨几行"推不出"轮胎压住作物行"：行距 38.2 cm 时 191 cm 恰为 5 个行距，两轮中心 ±95.5 cm 正落在 ±76.4 与 ±114.6 之间的行间。同时把"可跨车迁移"收窄为"模块可复用＋上车逐台确认"，相机内参/IPM 由"必然不同"改"待核验" | 本行 Hw-20；`docs/整车尺寸实测表_20260921.md` N1 与判定 2/3；v1.0 §4.1；AGENTS 下一步；缺口清单 R3 | 判据改为四项实测（轮迹对行线偏差 M15、胎面接地宽 M14、作物保护带、行驶跟踪误差），已进量表；`tools/geometry_check.py` 改为只报事实并配反例测试。**实测前论文与文档两侧都不许写压苗或不压苗** | Qoder（codex 09-21 再次复审 §3） |
| 2026-09-21 | Fw-8 / H2.3 补强（E2③） | SBUS 有效帧判据 = 帧头 `0x0F` + XOR **两条件** → **三条件**：再加 `UART1_Rec_Len == SBUS_DATA_LEN(35)`。原写法在短帧（部分帧）时，XOR 循环与 `rec_sbus_data[34]` 照读不误，而数组里留着**上一帧的旧尾巴**——旧尾巴本身是有效数据，所以帧头与 XOR 仍可能同时通过，而 16 个通道字是两帧的混合。与 H2.3 同源："收不全就不算收到" | telecontrol.c:142（"UART1_Rec_Len 算了但没用"这条编译告警随之消失，正是它现在被用上的证据） | ✅ 09-21 qoder 命令行 `UV4 -r`：**0 Error / 60 Warning**（基线 61，少的那条就是 UART1_Rec_Len 未使用），Code=44848（原 44840），hex+map 已再生，`USART1_IRQHandler` 在 map 中 342 字节。**待台架 B2 ④(a)(b) 两子情形**（浮空线/断线时不得刷新 sbus_last_ms，且短帧不得更新通道值）。**仍不依赖 byte[33] flag 极性**（Hw-17 未决） | Qoder（复审 E2③） |
| 2026-09-16 | Hw-19 行距与坡度 | 行距 30~60 cm → **30~40 cm**；坡地 5~15° → **0~15°** | 台账 §3 Hw-19；组会 deck 第 3 页；论文 ch02:14/ch05:8 待改 | 汇报人改 PPT 时现场更正（最高权威）；连带需重算 30~40 cm 下的通过性余量 | 用户+Qoder |
| 2026-09-15 | Hw-18 刀数与布置 | "3 侧刀 + 1 中间刀"(qoder 数错) → **2 侧刀 + 1 中间刀,共 3 把对应 3 条草带,仅中间刀可横移** | 台账 §3 Hw-18;组会 deck 第 7 页 | 汇报人口述确认,并与 retrofit.c lift_bits 三梁位、ch02:105"左右刀梁固定"交叉一致 | 用户+Qoder |
| 2026-09-14 | H2.3 / 新增 Hw-17 | SBUS 心跳 `retrofit_notify_sbus()`:IDLE 中断开头无条件调用 → 移入"帧头 0x0F + XOR 校验通过"分支内(原写法使浮空线乱字节刷新 sbus_last_ms,失联保护失效)。明确不用 byte[33] flag 做判据(极性未证) | telecontrol.c:161-171 | ✅ 09-14 命令行 `UV4 -r` 0 错误 / Code=44840;台架 B2 ④(a)(b) 两子情形待做 | Qoder(复审追写) |
| 2026-09-05 | Hw-9/9a/11 | 查固件定案:电推杆双向换向=6 路(T5+DR25 备用脚);T5 系改造新增语义、原车未用(retrofit.c:32);转向伺服=UART4 Modbus-RTU(uart4.c 已有完整协议) | — | — | ZCode |
| 2026-09-05 | Hw-9/9a/10 | 用户澄清:3 根电推杆=3 行刀升降(被动进土);T5 三路继电器用途不明(新 B6 项);行走电机控制与固件同款(Hw-10 解除) | — | — | 用户+ZCode |
| 2026-09-05 | Hw-7~11 | 用户确认四大实车部件(相机/电推杆/4×行走/转向伺服)并给购买链接;固件三处假设(步进→伺服、刀继电器→电推杆换向、PWM直驱→转把电平)标记待改 | — | — | 用户+ZCode |
| 2026-09-05 | Fw-10 IWDG | 双套 → 单套(main.c 1s) | retrofit.c | Keil 重编译 0 错误 Code=44544 | ZCode(ea5106a) |
| 2026-09-05 | — | 建表 | — | — | 初版(依据 firmware/retrofit.c + 原理图核对 + 审查记录) |

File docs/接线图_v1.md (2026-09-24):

# 整车接线图 v2(RDK X5 版,全车元件)

> 依据:`firmware/retrofit.c` pin map、`firmware/大车proj/大车/USER/main.c`(原车外设清点)、`docs/refs/原理图PDF核对.md`(大板.pdf 逐页提取)、缺口清单 E2 选型。
> v2 变更(2026-09-05):车端网关全部按 **RDK X5** 表述;新增**电源系统**、**行走/转向/人机等原车系统**章节,覆盖整车所有元件。
> **带 ⚠ 的条目接线前必须实物确认;原车(除草改造之前)已有接线原则是"不动的照原样,动的只动下表新增部分"。**

## 0. 全车系统总览

```
                       ┌────────────────────────── 48V 电池组 ──────────────────────────┐
                       │ (46~54V)                                                      │
                  XT60 T1/T2(并联)                                                    │
                       ▼                                                               │
        ┌─────────────────────────────────────────┐                                    │
        │          大板 STM32F407ZGT6              │                                    │
        │  电源树: 48V ─ U24/U23 ─▶ 24V ─┬─ MOTOR_1(经 SL1 继电器) ─▶ 前轴电机控制器×2 │
        │                               └─ MOTOR_2(直接)         ─▶ 后轴电机控制器×2   │
        │           48V ─ U25 ─▶ 12V ─▶ U26/U27 ─▶ 5V(5_A_V/5_B_V) ─▶ 3.3V           │
        │                                                                            │
        │  控制/反馈:                                                                 │
        │   TIM1 4ch PWM ────────────▶ 4×行走电机控制器(pwm_veloc)                    │
        │   UART4 19200 ────────────▶ 转向伺服电机控制器(send_angle)                  │
        │   485 #1(PA2/PA3,经DR25) ◀─ 轮角编码器(绝对值,9600,USART2)                  │
        │   I2C1(U17 ADS1115) ◀────── 4×轮角电位计(AD1~4,经DR25) + 刹车电流/电池电压   │
        │   I2C2(U18 ADS1115) ◀────── AD5=ACS712 电机电流 / AD6=刹车·电池电压         │
        │   TIM3 捕获(PA6/PA7/PB0/PB1) ◀─ 4×行走电机霍尔(经 LM393,DR25 J1/J2)         │
        │   UART5 115200 ───────────▶ HMI 串口屏(TJC,txt/j0 控件)                     │
        │   PA5─SL1 / PF10─SRD1 / PF8─SRD2  继电器驱动                                 │
        │   SBUS 接收机(原车输入)─ 遥控;MP3 模块─语音提示;示廓灯/蜂鸣器                  │
        │                                                                            │
        │  ★ 除草改造新增(Retrofit):                                                  │
        │   USART6(PC6/PC7,TTL) ──▶ RDK X5 UART ★链路核心★                            │
        │   PD4/5/6 ─ 74HC245 ─ T5(7/9/11) ─▶ 刀继电器×3(光耦,高有效=提刀)             │
        │   PB6/PB5/PB7 ──────────▶ TB6600 步进驱动器 ─▶ 中间刀滑轨 NEMA17             │
        │   PD15/PD10/PD11 ◀── 限位开关×3(常闭,接地)                                  │
        └─────────────────────────────────────────┘                                    │
                       ▲ USB-C 5V(建议独立 48→5V/4A Buck,见 §1-P5)                      │
        ┌────────────────┴───────────┐         5GHz WiFi/UDP                          │
        │  RDK X5(车端网关)           │ ◀─────────────────────────▶ PC(笔记本,pc/main.py)│
        │  camera(MIPI CSI/USB,待定) │      NAV/TOOL/ESTOP→UDP9000,RDK→PC UDP9100     │
        └────────────────────────────┘
```

## 1. 电源系统(全车供电,先看这里)

| # | 电源轨 | 链路(原理图已证实) | 用电元件 | 注意 |
|---|---|---|---|---|
| P1 | 48V 输入 | 电池 → **XT60 T1/T2(并联,无切换)** → VIN(46~54V) | 全车总入口 | XT60 防反接靠 D3~D6 SS210 |
| P2 | 24V 电机电源 | 48V → **U24/U23(48_to_24 ×2)** → VCCIN_24_A_1/2 | → MOTOR_1 / MOTOR_2 → DR25 J1/J2 引出 → 4×行走电机控制器 | **MOTOR_1 串 SL1**(PA5 可断),MOTOR_2 不串——急停只能断前轴两轮动力,⚠ 后轴仍带电,需评估 |
| P3 | 12V | 48V → U25(48_to_12) → 12V 轨 | T5 排针 1/2 脚(刀继电器模块供电)、HMI 串口屏、MP3、LED_1、SRD2 触点侧 | 外接继电器模块从 T5 取电,建议模块独立供电并共地 |
| P4 | 5V/3.3V | 12V → U26/U27 → 5_A_V/5_B_V(各 1.5A) → 3.3V | 大板逻辑、74HC245、ADS1115、SBUS、MPU | 5_B_V 供继电器线圈驱动 |
| P5 | **RDK X5 供电(新增,⚠)** | **建议:48V → 独立 48→5V/4A DC-DC Buck → USB-C 给 RDK X5**(RDK X5 用 USB-C 5V 供电,峰值约 4A) | RDK X5 + 相机 | ⚠ **不要从 P4 的 5_A_V/5_B_V(1.5A)取电**——RDK 推流+推理时峰值电流会拉垮大板 5V 轨导致复位。Buck 到货后在台架先带载实测压降 |
| P6 | 电池采样 | 电池/刹车电压 → LM358 → AD6(U18) | 固件 bat 字段(当前占位 48.0,见参数台账 Fw-5) | — |

**上电时序(整车):** 电池开关/XT60 → 大板 48V 上电 → 各 DC-DC 轨建立 → U26/U27 5V → MCU 3.3V 复位释放 → main.c `SW_3=1` 闭合总继电器 → `delay_ms(1500)` 等 AD 稳定 → 外设初始化。**RDK 与 PC 独立供电,与大板共地(共地点见 §5)。**

## 2. 行走系统(原车,改造不接线,但要明白)

| 元件 | 大板侧 | 物理路径 | 改造影响 |
|---|---|---|---|
| 4×行走电机控制器 | TIM1 4 路 PWM(4kHz,pwm_veloc) | PWM 信号 + MOTOR_1/MOTOR_2 24V 经 **DR25 J1/J2** 电缆到控制器 | **ea5106a 已把 AUTO/ESTOP 门控加在 pwm_veloc 写入点**;ESTOP 时四轮 CCR=0 |
| 4×电机霍尔 | LM393 → PA6/PA7/PB0/PB1 | Hall_1/2=J2 脚 6/19(左前/右前),Hall_3/4=J1 脚 6/19(左后/右后) | retrofit TIM3 捕获用于轮速估计与 c_per_pulse 标定(台账 Fw-3) |
| 电磁刹车 | SW_Stop(PA5 驱动链 + NBREAK1/NBREAK2 端子组) | 刹车线串入 CH3.96_2P 端子,原车逻辑 | ⚠ NBREAK 实车接法 B6 ①② 待拍照确认 |

## 3. 转向系统(原车)

| 元件 | 大板侧 | 说明 |
|---|---|---|
| 转向伺服电机(1 个伺服控制 2 轮) | UART4 19200,`send_angle(adress, angle)` | 地址 4/1/2/3 = 左前/右前/左后/右后 |
| 轮角反馈 | 二选一:① 轮角电位计 → DR25 AD1~4 → U17 ADS1115(I2C1=PB8/PB9);② 绝对值编码器 → **485 第 1 路(PA2/PA3)经 DR25 J1/J2 A_1/B_1**(USART2 9600) | `flag_sensor` 决定走哪路;第二辆车可能未装传感器(代码注释) |
| AUTO 转向 | **改造当前只控差速(vL/vR),不改前轮转角** | AUTO 时伺服保持直行位置;后续若要转角参与,是 D 级新任务 |

⚠ **注意:** 485 第 1/2 路总线经 DR25 电缆出板(A_1/B_1、A_2/B_2)——**不要**把 RDK 链路挂到这两对线上,只允许用第 4 路(U7/T6)或纯 TTL 点(见 §5)。

## 4. 作业系统(除草改造,2026-09-05 按实车部件修订)

> **实车确认:中间刀左右微调 = 直流伺服(位置模式,PUL/DIR),刀升降 = 48V 电推杆(非步进+刀继电器)。** 详情见参数台账 Hw-7~Hw-9,以下按实车重写,❓为待用户确认项。

| 大板引脚 | 板内路径 | 引出点 | 实车执行元件 | 注意 |
|---|---|---|---|---|
| PB6(TIM4_CH1, 2kHz 脉冲) | 板内直出,⚠ 引出点未在原理图找到 | — | **伺服驱动器 PUL**(60法兰 400W 48V,位置模式) | 电子齿轮→重标 Fw-1 |
| PB5 | 同上 ⚠ | — | **伺服 DIR** | 极性台架定 |
| PB7 | 上电即拉高使能 ⚠ | — | **伺服 EN** | 伺服报警/EN 逻辑按手册 |
| PD4/PD5/PD6(原刀继电器 3 路) | 74HC245 U6→T5 7/9/11(**V3.3 已贴片,链路通**;固件为改造新增语义,T5 后端负载仍需 B6 实物确认) | T5 | **3×电推杆 BST-YF-L(48V,200mm,10mm/s)→ 3 行刀升降,由车外接继电器板控制** | 接入方式待继电器板照片(路数/触发极性/现有触发源):电平触发→我们输出并联接入;固件伸/缩互锁,ESTOP 强制全提;10mm/s 全程 20s→**急停提刀时间指标重评** |
| PD15/PD10/PD11 | U5 输入缓冲(**V3.3 已贴片,链路通**) | T4/T10 | 限位开关(保留作保险;伺服自带编码器) | 常闭型;PD15 原点疑似 MCU 直连不受 U5 影响,接前顺带确认 |
| 伺服供电 | 48V 直接取电池(经空开/保险) | — | 伺服主回路 48V | 400W 峰值电流大,线径够粗 |

## 4A. 原步进方案的差异备忘(固件 retrofit.c 待改清单)

1. `STEPPER_STEPS_PER_MM=25.0` → 伺服电子齿轮等效值,台架重标(Fw-1);
2. 刀输出语义:`lift_bits` 3 位(梁1-3)→ 电推杆伸/缩换向位,协议 TYPE_TOOL 的 lift 字段含义同步改(common/protocol.py 与 C 两端);
3. 限位闭锁逻辑(`stepper_update` 读 PD15/10/11)保留,但伺服模式下主要防撞保险;
4. 相机:`pc/main.py` FrameSource 与 stream 适配 USB UVC(MJPG),不再走 CSI/树莓派管道(Hw-8)。

## 5. 控制链路(RDK X5 ←→ 大板 ←→ PC,核心链路)

| 连接 | 大板侧 | RDK X5 侧 | 说明 |
|---|---|---|---|
| 大板 TX → RDK RX | **PC6**(USART6_TX) | 40-pin 排针 UART 收(RDK X5 具体引脚号到货后从官方 pinout 确认,`/dev/ttyAMA?`) | 3.3V TTL 直连,115200 8N1 |
| 大板 RX ← RDK TX | **PC7**(USART6_RX) | 40-pin UART 发 | 同上 |
| 共地 | GND | GND | **必须共地**(建议与大板 5V/3.3V 域就近一点共地,别借大电流回路) |

⚠ **两个冲突/风险点:**
1. **PC6/PC7 兼接 485 收发器 U7**(DI=PC6/RO=PC7,A_4/B_4 → T6 排针)。U7 若贴片在用,其 RO 会持续驱动 PC7 与 RDK TX 打架 → **B6-5 确认 U7 实物,不用则不贴/拆掉,或确认其 /RE 脚默认禁用**。TTL 引出候选:DR25 J2-18(PC6_OUT)/J1-18(PC7_OUT),经 245 缓冲,245 方向需核对(输出方向对 PC7 作 RX 不利),万用表敲定。
2. **485 第 1/2 路经 DR25 出板挂原车设备**(编码器等)——严禁把 RDK 链路接进 A_1/B_1、A_2/B_2。

| 连接 | RDK X5 侧 | PC 侧 | 说明 |
|---|---|---|---|
| 视频流 | **USB3.0 UVC 相机(实选 DCXW20030,1080p60 MJPG,镜头 2.8mm 无畸变)→ RDK USB3.0 口,v4l2/MJPG 直读** → 推流 **MPEG-TS over UDP:5000**(ea5106a 已改 TS,OpenCV udp:// 可解码) | pc/main.py `udp://@:5000` 接收 | 免驱免 MIPI;60fps 对时延分段(F3)有利;相机装 0.9m 机位,IPM 标定台账 Pc-1 |
| 控制流 | UDP 9000 收 NAV/TOOL/ESTOP(heartbeat 兼容),UDP 9100 发 STATUS(0x10,20Hz) | pc/main.py 发/收 | 5GHz 链路,B8 验收:丢包<1%,p95<50ms |
| RDK 联网 | RDK X5 无线模块能力**到货验机确认**(E2.2 四项验机含推流);若 5GHz 不达标 → E4 定向天线/CPE | PC 开 5GHz 热点 | — |

`vehicle/` 代码现状按树莓派写(serial_dev=/dev/ttyAMA0、gstreamer 管道、dtoverlay)——**RDK 适配已登记台账 Hw-6**,到货后改 config.yaml/桥接/推流三处。

## 5A. 实物近照核对(2026-09-05,三张近照,`docs/近照A/B/C标注.jpg`)

板号丝印 **WANYUAN ROBOT V3.2 2025/04**。近照证实/新发现:

| # | 事实 | 对改造的影响 |
|---|---|---|
| 1 | **U7(485 第 4 路,PC6/PC7 那路)已贴片** | ⚠️ **09-23 撤回本行旧文**：旧文说"每路配 TTL/485 选型 0R：U7 路丝印 `R23(TTL)/R13(485)`、U8 路 `R24/R14`，若焊 TTL 选项就是最好情况"——那是**照片推断**，位号归属错了，我照抄过。以 `大板.pdf` p0 厂商装配注为准：**U7 块是「485: R15、R16默认焊接」+「R25、R26默认不焊接」两条并联支路**（R15/R16 经 485 芯片，R25/R26 是 TTL 直通 T6）；**R13/R14/R23/R24 属 U8 块**（「R13、R14默认不焊接」「R23、R24默认焊接」「U8及相关器件默认不焊接」）。⇒ ①"U8 疑似空焊"是**设计如此**，不是 V3.2/V3.3 版本差异，本表 #2 的对比结论随之作废；② 09-23 作者焊 R25/R26 = 走厂商预留的 TTL 直通，方向对；③ **但 R15/R16 仍在 ⇒ U7 的 RO 还挂在 PC7 上**，要拆 R15/R16 才算真旁路。MAX13487 引脚（PDF 直读）：1 RO / 2 RE# / 3 SHDN# / 4 DI / 5 GND / 6 A / 7 B / 8 VCC —— **有 RE# 与 SHDN#**，我上一轮"该系列无 DE/RE"的说法不准（它是自动换向、无 DE，但接收使能与关断脚是有的） |
| 2 | ~~U5/U6 疑似空焊~~ → **✅ 09-05 确认:实车板为 V3.3(2025/06),U5/U6/U17 全部已贴片**(近照空焊判断对应 V3.2 板,V3.2 为备板不上车) | PD4/5/6→T5 刀输出链路**通**;T4/T10 限位输入**通**;**"U3→DR25 绕行方案"降级为备用**。V3.2 备板与实车存在 U5/U6/U17 装配差异,**切勿拿 V3.2 的空焊结论推断实车,备板仅作比对参考** |
| 3 | **T7 = "下载+串口调试"(白 6P)**,板上有明确丝印 | 旧固件 printf 曾用 USART6(见集成说明)→ **T7 大概率就是 USART6 的 TTL 引出点,RDK 串口优先接这里**。万用表量 T7 各脚 ↔ PC6/PC7/GND/3V3 通断即可定论 |
| 4 | T3 = SBUS 输入(GND/VCC/SBUS/PWM);T9 = 遥控器/温度;T10 = 编码器;T11 = 温度传感器;MPU 排针 = 5V/GND/SCL/SDA(加速度+陀螺) | 接线图 §3/§6 各元件位置已可对号入座 |
| 5 | **DTU 插座**(RST/GPS/WAK/TXD/RXD/GND/5V)与 **NRF24L01 插座**均在板上 | 备用无线链路选项;若 5GHz WiFi 不达标(B8),可评估 DTU 数传 |
| 6 | DS1 三位拨码已贴片(ON/OFF 可拨) | B6④ 的 AUTO/MANUAL 判据可用 DS1 实现(接 PF12/PF14/PF13) |
| 7 | J2 脚位丝印直读:D2/D1=CAN、BR1+=刹车、RL=继电器、AS1/AS2=轮角、H1/H2=霍尔、AD1/AD3=模拟 | 与原理图核对 §11 一致;B6 引脚敲定更快 |
| 8 | 板版本:近照 V3.2(2025/04),完整板 **V3.3(2025/06)**,均比 SchDoc 新 | 位号以 V3.3 实物为准(如选型电阻编号与 PDF 报告的 R15/R16 不同代) |
| 9 | ~~U17 疑似空焊~~ → **✅ V3.3 上已贴片** | 轮角电位计 AD1~4、电池电压/刹车电流 ADC 链路可用;Fw-4(电流,经 U18)/Fw-5(电压)恢复"接线即测";顺带确认 U18 焊况 |

## 6. 人机与辅助(原车,不动)

| 元件 | 接口 | 说明 |
|---|---|---|
| HMI 串口屏(TJC) | UART5 115200,`HMISends` | 速度/角度/报警文本显示 |
| SBUS 遥控接收机 | 原车 SBUS 输入 → telecontrol.c | MANUAL 指令源;AUTO/MANUAL 切换判据待 B6④ |
| MP3 语音模块 | PG0~PG3/PG5~PG8,DACL/DACR → 喇叭 | 障碍报警等语音提示 |
| 示廓灯 / 蜂鸣器 | PC0→LED_1、PG5、BEEP | 原车 |
| DS1 三位拨码 | PF12/PF14/PF13(SchDoc 写 PF11 是错的) | 预留模式选择 |
| 推拉杆等原车执行机构 | PA11/PD3/PF6/PF7 等预留输出 | 原车逻辑,改造不触碰 |

## 7. 接线操作顺序与上电前检查单

**顺序:** 先共地 → 后信号 → 最后功率。具体:
- [ ] P5:RDK 独立 48→5V/4A Buck 到位,台架带载实测(不得由大板 5V 轨供电)
- [ ] 共地:大板 GND、RDK GND、继电器模块 GND、电池负极 同电位(逐点量 <0.1Ω)
- [ ] ~~U5/U6/U17 空焊~~ ✅ 实车板 V3.3 已贴片;V3.2 为备板(装配有差异,不作为实车依据)
- [x] ~~U7 路 R13/R23 哪个有焊料~~ → **09-23 作废：位号问错了**。`大板.pdf` p0 厂商注：U7 块是 **R15/R16（485 支路，默认焊接）** 与 **R25/R26（TTL 直通 T6，默认不焊接）** 两条并联路；R13/R14/R23/R24 属 U8 块。作者 09-23 已焊 R25/R26（选对），**R15/R16 仍未拆**。
- [ ] **量 A_4/B_4 是否仍被 U7 驱动（09-23 改：原"拆 R15/R16"待办作废，实板 R15/R16 未焊）**：① 断电量 A_4–B_4 间电阻；② 带电、X5 不接，量 A_4、B_4 对 GND；③ 1k 把 A_4 拉向 GND 看拉不拉得动。拉不动=U7 在驱动，需改接真 TTL 脚或拆 U7。判据仍是双向 + `rx_bad` 长期为 0。
- [ ] **链路准入判据（09-22 新增，替代上面那件）**：只接 共地 + X5 Pin8(TX)→大板 PC7(RX) 一根信号线，X5 上 `python3 -c` 循环往 `/dev/ttyS1` 灌字节，同时用**第二个 USB-TTL 并到 PC7 上当探针**（仓库里 USB-TTL ×2 已到），在 PC 侧看波形：
      - 干净 115200 波形 + 大板能回 STATUS → RO 没抢，链路可照常接；
      - PC7 静态被顶在 3.3V、"0" 电平抬到 1~2V、或探针全收到 1 → **U7 在驱动 PC7，冲突确认**。此时**不要硬上**，三档处置按侵入性递增：① 查 MAX13487 手册找关断脚、把它拉成停（拆电不拆件，可逆）；② 拆掉 485 那一颗选型 0R（拆件，装回前拍前后照并登记台账）；③ 换链路串口 = **改设计**，回来说一声，走 zcode 审。
      - 冲突没排除前，"车不理电脑"这个症状不能算通；同时它和 `bridge.py:200` 的 `allowed_sources` 白名单症状一样（白名单是干净丢弃、对顶是收不到或 CRC 全错），**先用探针分根因再改配置**。
- [ ] **T7 还是 T6 → 09-23 作者改为"焊 R25/R26 各一颗 0Ω，用 T6"**：T7 通断仍未量（保留待办，将来若回到 T7 可省掉这两颗电阻）。⚠️ 本条**未闭环**，缺两样：① R25/R26 跨接的是哪两个网络（原理图提取无此位号，需照片+说明）；② **U7 的 RO 是否仍在驱动 PC7**——焊通一条新路不会让 485 那颗 R13 停下来。判据见上一条与台账 Hw-1：**双向都通 + `rx_bad` 长期为 0** 才算链路可用，单向收到 STATUS 不算。
- [ ] T5 第 7/9/11 脚 ↔ PD4/5/6 复核(±1 行风险)
- [ ] PB5/PB6/PB7 引出点找到(找不到 → 飞线决策)——滑台伺服若走 Modbus-485 则此三项降级为备用
- [ ] 限位开关引出点(T4/T10)确认,常闭型
- [ ] 外接继电器板照片(路数/触发极性/现有触发源)发 ZCode 判读,定 6 路接入方式
- [ ] NBREAK1/NBREAK2 实车接法拍照记录(B6 ①②)
- [ ] SL1 只断 MOTOR_1 的风险评估:后轴 MOTOR_2 急停覆盖缺口是否需补(断电机控制器控制电或加继电器)
- [ ] RDK UART 引脚映射确认;图传 MPEG-TS over UDP:5000 收发对通
- [ ] 继电器模块×3 光耦型、高有效、独立供电
- [ ] TB6600 细分数登记台账 Fw-1;限位安装方向与 DIR 正负对上
- [ ] 全部完成后:断开电机动力(拔 MOTOR_1/MOTOR_2 或吊起车轮),先跑 §5 链路对拍(`python common/uart_vectors.py --dump` 8 组向量),再带电试车

---
*变更记录:v2(2026-09-05)——全车元件版,RDK X5 化,新增 §1 电源/§2 行走/§3 转向/§6 人机;v1(2026-09-05)——初版,仅改造链路。*

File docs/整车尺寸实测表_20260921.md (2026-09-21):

# 整车尺寸实测表（2026-09-21 开表 · 同日更新）

> **为什么先量车**：`ch02:14` 要求"整机宽度不大于 60 cm"，而组会 deck 第 7 页与 `计划:11` 说"跨 4 行、清 3 条草带"。
> **09-21 汇报人已口述确认（见台账 Hw-20）：真实车宽 2.15 m、上代车宽 3.25 m —— 所以 `ch02:14` 那个 60 cm 是硬错误，差 3.6~5.4 倍。**
> 本表因此从"从头量 12 项"缩为"量剩下的 10 项"：宽度/轮距/车长/相机高度这类**车体尺寸基本已定**，剩下的重心移到了**田里的那一张横断面**（M3、M14、M15）——它决定伤苗率口径，而这不是量车能量出来的。
> 填完交给 `python tools/geometry_check.py` 复算。**注意该工具现在只报事实，不报结论**：`track_span` 给"轮距等于几个行距、还差多少"，压不压苗由人拿 M14/M15 判；`slide_reach_verdict` 按"单侧需求 ×2 = 总行程"算够不够。

## 〇、已确认，不用再量（09-21 口述，来源=汇报人现场）

| 项 | 值 | 备注 |
|---|---|---|
| 真实除草车 车宽 | **2.15 m** | 除 3 行；**现在在地里** |
| 上代除草车 车宽 | **3.25 m** | 除 6 行；**现在用来调固件/算法/通信**；只有一个刀推杆带丝杠左右微调电机 |
| 车长（两台同） | 162 cm | |
| 轮距 | **= 车宽 − 24 cm**（左右各减 12） | 真实车 191 cm、上代车 301 cm |
| 相机镜头离地高度 | **100 cm** | ⚠️ 与 `ch02:23`"低机位"矛盾，全文措辞要改 |
| 轮胎直径 | 60 cm | 轮心离地 30 cm |
| 刀中心↔车纵向中心线（M4/M5/M6） | **不用登记** | 可物理调节；但"能调"不等于"调到哪"，作业前仍要记录实际摆位 |

## 〇′、口述带出的两个新问题（比量尺寸更要紧）

- **N1 田块布置（09-21 复审后改口径）**：真实车轮距 191 cm，除以行距 30~40 cm 得 **4.8~6.4 个行距**——这是"两轮之间跨了几行"的算术，**推不出"轮子压过作物行"**。反例：行距 38.2 cm 时 191 cm 恰为 5 个行距，两轮中心 ±95.5 cm 落在 ±76.4 与 ±114.6 两条行线之间的行间。所以请拍一张**垄面/沟的横断面照片**并回答四件事：① 芍药种在垄上还是平作；② **轮胎接地条带的宽度**（胎宽，M14）与它相对作物行线的**横向偏差**（M15，轮居中于沟里还是压线）；③ 行距 30~40 cm 指的是**作物行间距**还是**垄间距**；④ 允许的最小**作物保护带**（刀/轮都不许碰的宽度）。→ 这四项决定 V4 伤苗率的分母口径；**在量出来之前，文档与论文都不许写"轮子压苗"或"轮子不压苗"**。
- **N2 样机身份 → ✅ 09-21 已定：论文样机 = 真实除草车（2.15 m，3 行）**，上代车（3.25 m）只作调试平台、不写进第 2 章尺寸。汇报人补充"两台车没区别，只是车宽不一样"——**该说法只对一半**：协议与帧格式、固件模式机代码、失联保护与状态新鲜度实现、控制律结构可**作为模块复用**，但搬到样机后仍须针对接线、执行方向、急停覆盖、供电、现场链路**逐台重新确认**（协议测试通过 ≠ 这台车确实停下来了；实测时延数值也不跨车继承）。**凡横向指标一律不可跨车引用**（轮距 191 vs 301 cm、轮迹与行的相对位置不同、有效双墙占比不同）。相机内参/IPM 属**待核验**：车更宽不是光学参数变化的充分原因，能否复用取决于相机/镜头/成像设置/安装姿态/坐标定义是否一致，当前档案不足，故按"样机重新标定"执行并写成核验要求。所以第 4/5 章每个对行偏差/伤苗数据都要标注采集自哪台车。

## 一、量具与规矩

- 卷尺 5 m + 直尺；**每个量至少量两次，两次差 >1 cm 就重量**。
- 车停在平地、刀处于**正常作业高度**（不是全提刀状态）时量横向尺寸。
- 所有长度单位 **cm**，保留 1 位小数。角度用手机水平尺或量角器，估到 ±2°。
- 每项拍照留档（照片里带卷尺刻度），文件名写进"照片"列。

## 二、仍需量的项

| # | 量什么 | 怎么量 | 填值 | 照片 | 这个数用来判什么 |
|---|---|---|---|---|---|
| M3 | **行距实测 s**（田里量，不是文档值） | 连续 4 行中心到中心，取平均与最小/最大 | | | 一切跨带算式的基准；也用来判 N1 里"行距"到底是哪个口径 |
| M7 | **三把刀各自的刃宽** | 刀刃最外缘之间 | | | 弹齿登记为 250 mm 五齿；**鸭掌铲未登记**，不补则 ch05 组1 对比条件不对等 |
| M8 | **中间刀滑台实测横移行程** | 拉到两端极限，量位移（**两端合计，不是单侧**） | | | deck 第 8 页写的"300 mm 行程"目前是从"300 mm 导轨"**推**出来的，不是量的 |
| M9 | **刀尖离地高度（提刀态 / 落刀态）** | 刀尖到地面 | | | 判"抬刀 50 mm 要 5 s"能不能读成"刀具 5 s 离土" |
| M10 | **推杆行程 ↔ 刀尖提升量的传动比** | 推杆缩回 X，量刀尖升 Y | | | 急停提刀时间指标必须按 Y 算，不按推杆速度算（R7） |
| M11b | **相机光轴俯角** | 量角器/水平尺，或拍已知距离的地面标记反算 | | | 高度已知 100 cm，缺俯角就无法算 IPM 与地面分辨率 |
| M12 | **相机纵向位置：前轴/前轮到镜头的距离** | 沿车纵向量 | | | 决定"看到的行"与"刀要走的行"之间的纵向滞后 |
| M13 | **（新增）上代车与真实车的刀头数与布置** | 数刀头 + 拍照 | | | 判"除 3 行/6 行"里的"行"是作物行还是草带，与 Hw-18 的"2 侧刀 + 1 中间刀"对齐口径 |
| **M14** | **（09-21 复审新增）轮胎接地条带宽度** | 量胎面实际接触地面那条带的宽度，不是轮胎外廓宽 | | | 判压不压苗必需：行距与轮距只给出行线位置，接地**宽度**才决定它是否覆盖某条行线 |
| **M15** | **（09-21 复审新增）轮迹相对作物行线的横向偏差** | 车停在拟作业位置，沿行线拉粉线，量轮中心到最近行线的垂直距离（左、右分别记，多停几次） | | | 直接判轮走沟还是走行；与**作物保护带宽度**一起才构成 V4 伤苗口径。多次记录同时给出行驶跟踪误差 |

## 三、填完要得出的四个判定

1. **跨几行、清几带**：用 M3 + M13 定口径，别再靠文档推。
2. **轮子压不压苗**：由 **轮距（已给）+ M14 胎宽 + M15 轮迹对行线的实际偏差 + 行驶跟踪误差**共同判定。`tools/geometry_check.py:track_span` 已改为**只报事实**（轮距等于几个行距、离整行距还差多少、几何上是否可能对得上行），**不再输出"压苗"结论**——09-21 撤回旧推论（行距 38.2 cm 时 191 cm 恰为 5 个行距，两轮正落在行间，说明"跨几行"推不出"压几行"）。伤苗率分母口径等这一条实测落地后再定，此前论文与文档两边都不许写结论。
3. **中间刀够不够横移**：**不要**默认"必须覆盖 ±s/2 再加保护带"。按拟补偿的**底盘残余横向偏差**、**刀具安全作业区**、**机械限位**三者定义需求；保护带通常是**限制**可用空间，不是必须越过的行程。算式：单侧需求 = 残余偏差 + 刀对行准量 + 安全余量，**总行程 = 2 × 单侧需求**（09-21 修的单位错误：旧实现拿两端总行程跟单侧距离比，行距 35/行程 30/保护带 5 会被报成"够"，而 30 cm 总行程单侧只有 15 cm）。用 `tools/geometry_check.py:slide_reach_verdict` 复算。
4. **急停提刀时间**：用 M10 的传动比换算刀尖离土所需时间，替换 deck 第 15 页与 B5 里按 10 mm/s 直接推的说法。

## 四、定完之后改哪里（顺序固定）

- 改 `ch02:14`（**≤60 cm 是错的**）、`ch02:23`（"低机位"）、`ch02:117`（"三刀覆盖整个行间断面"）→ 与实测一致并**点名样机是哪台车**；
- 改 deck 第 7、8 页（"跨 4 行 3 带""300 mm 行程"）；
- 定 V4 布样：按"每条带分别登记原始计数，再汇总"，**不得把三带合计改善全归因于中间刀**；
- 台账 Hw-14/Hw-20 由"🔴/🟡"改"🟢 已明"，并把 M3/M7–M15 逐项落进台账。

> **本表自己的勘误（09-21 复审后）**：① 表初版把"跨几个行距"直接写成"轮子必然压过若干作物行"，已撤回，判据改为 M14/M15 实测；② 初版对中间刀行程的需求写成"至少 ±s/2 + 保护带"，这是未经论证的默认，已改为按残余偏差/作业区/限位定义；③ 初版"可跨车迁移"的清单过强，已收窄为"模块可复用 + 上车逐台确认"。三条同时改进了 `tools/geometry_check.py` 与其测试。

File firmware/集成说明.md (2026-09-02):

# 大车固件除草改造集成说明（firmware/）

**状态（2026-09-02）：已在 Keil UV4 + ARMCC 5.06 编译通过（0 错误），完整集成版位于 `firmware/大车proj/大车/`，hex 已生成（OBJ/ 下）。以下集成步骤已在工作区副本中完成**，用户侧只剩烧录与台架标定。原 zip 里的旧 OBJ 会导致假链接错误（旧 usart.o 自带 USART6 中断），务必全量重编。

## 文件
- `protocol.c/h` — 0xA5 0x5A 帧解析/构建 + CRC16，与 `common/protocol.py` 逐字节一致
- `retrofit.c/h` — 全部新增功能（UART6 链路、双指令源、刀控联锁、看门狗、步进、轮速捕获、状态帧）

## 集成步骤（Keil）
1. 把 `protocol.c/h`、`retrofit.c/h` 加入工程（HARDWARE 组即可），Include Path 加 `firmware/`。
2. `main.c`：在外设初始化区（`delay_init(168)` 之后）加 `retrofit_init();`；主循环里接一个 1 ms 时基——最简单是用 `delay.c` 里现成的 SysTick：在 `delay_ms` 之外找个已运行的 1 ms 中断（或新建 TIM6 中断，148 行处已有 TIM6 空闲），在中断里调 `retrofit_poll_1ms();`。
3. **SBUS 心跳对接**：`telecontrol.c` 的 SBUS 接收成功处（`CHANGE_FLAG=1` 附近）加一句 `extern volatile uint32_t sbus_last_ms; sbus_last_ms = <当前 ms>;`（retrofit.c 顶部 extern 即可）。
4. **底盘指令注入（双指令源核心）**：`car_control.c` 的 `Out_Pwm()` 开头加：
   ```c
   extern uint8_t retrofit_mode(void);
   extern void retrofit_get_wheel_cmd(float *vl, float *vr);
   float vl, vr;
   if (retrofit_mode() == 1 /*AUTO*/) {
       retrofit_get_wheel_cmd(&vl, &vr);
       veloc[0]=veloc[2]=vl; veloc[1]=veloc[3]=vr;  /* 左前/左后=vl, 右前/右后=vr */
       return;  /* 跳过 SBUS 通道映射 */
   }
   /* MANUAL：原逻辑不动 */
   ```
   （`retrofit_get_wheel_cmd` 需在 retrofit.c 补一个两行实现，返回 `cmd_vl/cmd_vr`——留给你编译时加，或在移植时告诉我报错信息。）
5. **急停硬件线**：保留原 PA5 大继电器作为最后一级；ESTOP 状态下 retrofit 已强制提刀（PD4/5/6 全高），确认实车继电器常闭/常开与代码假设一致（13.3 待确认项①②）。
6. 编译目标零警告后，先用 USB-TTL 跑 `python common/uart_vectors.py --dump` 的 8 组向量对拍，再接树莓派。

## 台架验收（对应 v0.7 §3）
- 8 组向量：6 组有效帧正确执行，2 组坏帧被丢弃
- AUTO 中拔串口线 → 500 ms 内急停+提刀
- ESTOP 后软件发任何帧不能解除，必须 `retrofit_clear_estop()`（接按键）
- 步进：±20 mm 阶跃，百分表重复定位 ≤0.5 mm
- 轮速：手转轮子，PC 收到 0x10 帧速度值连续合理

## 本机已做的集成改动（均已编译验证）
1. `USER/main.c`：`retrofit_init()` 挂在 `TIM1_PWM_Init` 之后
2. `retrofit.c`：新增 TIM6 1ms 中断驱动 `retrofit_poll_1ms()`、`retrofit_notify_sbus()`、`retrofit_get_wheel_cmd()`
3. `SYSTEM/usart/usart.c`：旧 `USART6_IRQHandler` 改名停用、RX 中断关闭（USART6 归协议链路；**printf 串口让位，调试打印一律弃用**）
4. `HARDWARE/telecontrol/telecontrol.c`：SBUS 帧成功处调 `retrofit_notify_sbus()`
5. `HARDWARE/car_cotrol/car_control.c`：`Out_Pwm()` 开头注入 AUTO 模式四轮指令（`retrofit_get_wheel_cmd`），MANUAL 走原 SBUS 逻辑
6. `PWM.uvprojx`：新增 RETROFIT 组 + IncludePath

## 已知简化（台架时处理）
- `adc_current_a()` 的 AD5 读取要接 `iic.c` 的 ADS1115 驱动（工程里已有 U18 读法，返回电流换算系数台架标定）
- 电池电压 bat 固定 48.0 占位，接分压电阻 ADC 后改
- `STEPPER_STEPS_PER_MM`、`c_per_pulse` 两个系数台架标定
- TIM3 捕获若与 pwm.c 里被注释的旧代码冲突，确认旧代码保持注释

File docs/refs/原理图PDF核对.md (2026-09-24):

# 大板原理图 PDF 核对报告

来源：`D:\ai work\zcode\hardware_ref\大板\大板.pdf`（7 页，A4 横向，Altium 导出矢量图）。
方法：pymupdf 提取全部文字对象及坐标（逐页存于 `D:\ai work\tmp\page0~6.txt`），按坐标邻近区域匹配元件位号-网络关系；本报告所有结论均给出可复查的文字坐标证据。

## 页序确认（实际与任务假设不同）

| PDF 页(0基) | 内容 | 证据 |
|---|---|---|
| p0 | 4路485通讯 | "4路485通讯"、4×MAX13487 |
| p1 | CPU（STM32F407ZGT6） | "STM32F407ZGT6"×3 |
| p2 | IO/扩展（74HC245×N、DR25 J1/J2、LM393 轮速、T5/T4/LED_IN） | "74HC245D"×5、"DR25-公头"×2 |
| p3 | 传感器/AD（TJA1050、MP3、ADS1115、DS1、EEPROM） | "TJA1050"、"ADS1115"×2 |
| p4 | 电源+继电器（XT60、48_to_24/12、SL1/SRD1/SRD2、ACS712） | "XT60"、"48_to_24"、"SLA-05VDC-SL-A" |
| p5 | 外设连接器页（MPU/DTU/T6/T8/T11、SBUS/PWM，含 SL1/SRD/DS1 丝印） | "COMPU"、"COuart0sbus" |
| p6 | PCB 预览（几乎无矢量文字） | "Board" |

下文页码用 p0~p5（0 基）。

---

## 1. PA5 → R149 → SS8050 → SL1（大继电器）——驱动链证实，触点用途与 SchDoc 不同

- p4 坐标区 (460~570, 370~520)：`PA5_PWM1 → R149(1K) → NPN4(SS8050) → SL1 (SLA-05VDC-SL-A)`，线圈电源 5_B_V，续流 D9(SS14)/D25/D26(SS34)。
- **触点不是切换 XT60 T2**。SL1 触点两侧网络是 `MOTOR_1_1` 与 `MOTOR_1_2`（跨接 0R R4、SS210 D23）：`MOTOR_1_1` 来自 `VCCIN_24_A_1`（48_to_24 U24 输出，经 0R），`MOTOR_1_2` 接 DR25 **J2 引脚 12/13（MOTOR_1_2）与 24/25（MOTOR_1_1）** 引出。即 SL1 是串在电机控制器 24V 供电回路（MOTOR_1）上的大继电器；T1/T2 XT60 只是 48V VIN 输入（两者并联，无切换逻辑）。
- 另注意 p4 右侧同结构有 `NBREAK1 / CONBREAK1（CH3.96_2P，丝印"强制不刹车1"）+ SW_IN + SW2/SW3` 网络，属于刹车串入端子组（见第 2 条）。
- **与 SchDoc 差异**：SchDoc"SL1 切换 T2 电机电源"证伪；实际 SL1 切 MOTOR_1 的 24V 供电通断。

## 2. PF10 → NPN → SRD1 主继电器；NBREAK2——证实

- p4 (496~650, 216~300)：`PF10_OUT → R6(1K) → NPN2(SS8050) → SRD1 (SRD-05VDC-SL-C)`，线圈 5_B_V，线圈回路串 `CONBREAK2（NBREAK2，CH3.96_2P 端子）`。
- NBREAK2 是主继电器控制回路的外接断点（旁边 SW_IN/SW3、R1/R2 0R 只焊一个默认 R1、丝印"强制不刹车1"）——急停/刹车开关可串入此处。与 SchDoc 判断一致，更准确说是"刹车串入端子"。

## 3. PF8 → SRD2；PC0 → LED_1——证实

- p4：`PF8_OUT → R8(1K) → NPN3(SS8050) → SRD2 (SRD-05VDC-SL-C)`（触点侧 12V/5_B_V）。
- p4：`PC0 → R148(1K) → NPN1(SS8050) → LED_1 (3mm_led, 12V)`；旁边同结构还有 PG5 一路 LED 驱动。

## 4. 485 四路 MAX13487 映射——全部证实；U7 A_4/B_4 → T6 排针（无外设痕迹）

- p0：U10=PA2/PA3→A_1/B_1（T8）、U9=PC10/PC11→A_2/B_2（T8）、U8=PC12/PD2→A_3/B_3（T6）、**U7=PC7_485(RO)/PC6_485(DI)→A_4/B_4**（R15/R16 0K 串接、R71/R72 120R 端接、D21/D22 SMF6.0CA TVS、R79/R80 10K）。
- U7 的 A_4/B_4 走到 p0 右下 **T6（2.0_2*4P 排针，8 脚）**，T6 另两对脚为 A_3/B_3；p0 还有 T8（A_1/A_2/B_1/B_2）、T11（2.54_1*3P，UART4/PD12/PF5）、DTU Header-7、MPU 8P（PA0/PA1/PB8/PB9/PF0/PF1/RXD/TXD/WAK/RST/GPS/PG12/PG13/I2C2）。
- **PDF 中无任何 T6 外接设备型号痕迹**——只是预留 485 外接口。结论：USART6(PC6/PC7) 是否空闲取决于实车 T6 是否插线（另注意 485 第 1/2 路还并到了 DR25 J1/J2 的 A_1/B_1、A_2/B_2，见第 11 条）。
- **⚠️ 09-23 补：本文件此前漏抄了 U7/U8 块的厂商装配注，导致台账/接线图把位号归属搞错过一次。** p0 原文四条（坐标实测）：`485: R15、R16默认焊接`(x410,y379)、`R25、R26默认不焊接`(x410,y393)、`R13、R14默认不焊接`(x403,y221)、`R23、R24默认焊接`(x403,y206)，另有 `U8及相关器件默认不焊接`(x518,y206)。⇒ **U7 块有两条并联支路**：R15/R16 = 经 485 芯片（默认通），R25/R26 = **TTL 直通 T6**（默认断）；**R13/R14/R23/R24 属 U8 块**，与 USART6 无关。"U8 空焊"是设计如此，不是版本差异。MAX13487 引脚由 PDF 直读确认：**1 RO / 2 RE# / 3 SHDN# / 4 DI / 5 GND / 6 A / 7 B / 8 VCC**（有接收使能与关断脚，非"无 RE/SHDN"）。

## 5. SW_reserv_CH1-8 → 74HC245 → T5——部分证实（网络名不同，T5 脚号已定位）

- p2 U6 (74HC245D) 区域 (470~620, 200~290)：输入 A0..A7 = **PD7,PD6,PD5,PD4,PD3,PE4,PE5,PE6**，输出 B0..B7 = PD7_OUT…PE6_OUT。**PDF 中不存在 "SW_reserv_CHx" 网络名**（该命名可能来自 Exp 板或 SchDoc 旧称）。
- T5（2.0_2*8P，16 脚，(690~790, 200~285)）：1/2=12V；左列（奇数）≈ **3=PE4_OUT、5=PD3_OUT、7=PD4_OUT、9=PD5_OUT、11=PD6_OUT**、13=PD7_OUT、15=GND 侧；右列（偶数）≈4=PE5_OUT、6=PE6_OUT、8/10=CANL/CANH、16=GND（脚号按行坐标推断，±1 行）。
- 即 PD4/PD5/PD6 对应 T5 的 **7/9/11 脚**（奇数列）。

## 6. 轮速 Hall→LM393→H_out→PB0/PB1/PA6/PA7——证实

- p2 (390~800, 60~140)：U20(LM393B)：Hall_1→H_out1→R7(0R)→**PB0**；Hall_2→H_out2→R5(0R)→**PB1**（2.5V 基准 R34 30k）。
- U21(LM393B)：H_out3→R10(0R)→**PA6**；H_out4→**PA7**（PA7/H_out4 同在 U21 区域 (740~800, 60~110)）。
- Hall_1-4 来自 DR25：J2 6/19 脚=Hall_1/Hall_2（丝印"左前/右前"），J1 6/19 脚=Hall_3/Hall_4（"左后/右后"）。

## 7. CAN 与 ADS1115——证实（U18 通道细节更正）

- p3 (330~520, 230~300)：U13 TJA1050：`PD1→TXD(pin1)`、`PD0→RXD(pin4)`（旁注 `PD0:CAN1_RX / PD1:CAN1_TX`），CANH/CANL + R136 120R，注释"去掉R107,R108"。
- U17 ADS1115：I2C1 = **PB8(SCL)/PB9(SDA)**，AIN0..AIN3 = AD1/AD2/AD3/AD4，ADDR→GND，5V_32 供电（C5 100nF）。✓
- U18 ADS1115：I2C2 = **PB10(SCL)/PB11(SDA)**，AIN0=**AD5**、AIN1=**AD6**、AIN3=**PWM_DC**（页注：AD6=刹车电流/电池电压、AD7(3.3V)=3.3V 电压、AD8(PWM_DC)=遥控电压）。SchDoc"AD5/AD6/PWM_DC"证实，PWM_DC 实为 AIN3（AD8 通道）。

## 8. ACS712 与 LM358——证实

- p4 (630~800, 420~520)：U22 (ACS712ELCTR-05B)：IP+/IP- 串 **MOTOR_2_2 回路**（R27/R28 0R），`VIOUT → AD5`（C15/D7/R11 10K/R12 1K 滤波，AD5 网络坐标 683,499）。✓
- U19 (LM358B, p4 (300~430, 420~470))：OUT1/OUT2 输出至 AD6 相关网络，+A3.3V 供电。✓

## 9. 拨码 DS1 / PD9-PD15 / MP3——部分证实，DS1 有更正

- p3 (630~760, 310~370)：DS1 = **DSIC03LS-P（3 位拨码）**，开关 1/2/3 = **PF12 / PF14 / PF13**，4/5/6=GND。SchDoc"PF14/PF13/PF11"中 **PF11 证伪，实为 PF12**。
- p2 (460~800, 415~500)：PD9/PD10/PD11/PF3 → U5 (74HC245) → PD9_IN/PD10_IN/PF3_IN…，另有 PD12_IN/PD13_IN/PD14_IN 去 **T4**（2.0 排针，含 LED_IN1/12V，p2 (698~800, 455~500)）；**T10** 在 p3 (690~740, 180~200) 一带。方向与 SchDoc"备用输入 PD9-PD15 → T4/T10"一致。
- MP3 模块 MP3（COMP3，18 脚，3.3_MP3 供电，SPK+/SPK- 经 R89 0K，DACL/DACR）：引脚为 **PG0,PG1,PG2,PG3,PG5,PG6,PG7,PG8**（p3 (30~180, 90~130)）。SchDoc"PG3-PG8"不完整（PG0/PG1/PG2 也在；未见 PG4）。

## 10. 电源树——证实

- p4：T1/T2 两个 XT60 输入 VIN（丝印 `VIN=46V~54V`，D3~D6 SS210）→ **U24/U23（48_to_24，R114/R115 6.8K 反馈，LED_24/LED_24_B）输出 VCCIN_24_A_1 / VCCIN_24_A_2** → 经 0R → **MOTOR_1_1 / MOTOR_2_1** → DR25 J2/J1 引出（外接电机控制器）。
- **U25（48_to_12）→12V** → **U26/U27（12V→5v_temp）** → **U14/U15 (LP5300B6F)** → 5_A_V / 5V_32；另有 5_A_V(1.5A)/5_B_V(1.5A) 分轨、3.3V。与 SchDoc 电源树一致（48_to_12 输出 12V，5v_temp 由 U26/U27 产生）。

## 11. XT60 T1/T2 与 DR25 J1/J2 引脚-网络表（实车接线用）

两个 XT60 均为 4 脚：+ = VIN(46~54V)、- = GND（另有 GND 焊点脚）；T1/T2 并联，无切换。

**DR25-公头 J2**（电机1/前轴侧，Hall_1=左前、Hall_2=右前）：

| 脚 | 网络 | 脚 | 网络 |
|---|---|---|---|
| 1 | B_1(485) | 14 | A_1(485) |
| 2 | B_2(485) | 15 | A_2(485) |
| 3 | PE2_OUT | 16 | PC8_OUT / PE11_OUT* |
| 4 | PC4_OUT / PF6_OUT* | 17 | PC3_OUT / PF7_OUT* |
| 5 | PE0_OUT / PE8_OUT* | 18 | PC6_OUT / PE9_OUT* |
| 6 | Hall_1 | 19 | Hall_2 |
| 7 | AD1 | 20 | AD3 |
| 8 | GND（旁 5_B_V） | 21 | GND |
| 9 | PF1_IN / PA4_IN* | 22 | PE13_IN / PC3_IN* |
| 10 | PE14_IN / PC2_IN* | 23 | PF2_IN / PC1_IN* |
| 11 | SW2 | 24 | MOTOR_1_1 |
| 12 | MOTOR_1_2 | 25 | MOTOR_1_1 |
| 13 | MOTOR_1_2 | 26/27 | GND |

**DR25-公头 J1**（电机2/后轴侧，Hall_3=左后、Hall_4=右后）：

| 脚 | 网络 | 脚 | 网络 |
|---|---|---|---|
| 1 | B_1(485) | 14 | A_1(485) |
| 2 | B_2(485) | 15 | A_2(485) |
| 3 | PE3_OUT / PA12_OUT* | 16 | PC9_OUT / PE14_OUT* |
| 4 | PC4_OUT / PF6_OUT* | 17 | PC3_OUT / PF7_OUT* |
| 5 | PE1_OUT / PA11_OUT* | 18 | PC7_OUT / PE13_OUT* |
| 6 | Hall_3 | 19 | Hall_4 |
| 7 | AD4 | 20 | AD2 |
| 8 | GND（旁 5_B_V） | 21 | GND |
| 9 | PE12_IN / PF15_IN* | 22 | PF0_IN / PF12_IN* |
| 10 | PE10_IN / PC5_IN* | 23 | PA5_IN / PC4_IN* |
| 11 | SW2 | 24 | MOTOR_2_1 |
| 12 | MOTOR_2_2 | 25 | MOTOR_2_1 |
| 13 | MOTOR_2_2 | 26/27 | GND |

（\* = 该脚旁出现两个网络标签，PDF 文字坐标无法唯一归属；MOTOR_x_1 为 48_to_24 供电进线，MOTOR_x_2 为经 SL1/SRD1 触点后的出线。J1 第 2 列另有一组不带 _IN/_OUT 的短名 PF0/PF1/PA4/PA5/PC1-PC5/PE10/PE12/PE13/PE14（坐标 x≈270-273 列），为 J1 第二排引脚网络。）
**注意**：485 第 1/2 路（A_1/B_1、A_2/B_2）直接引到了 J1/J2——DR25 电缆里含 485 总线。

## 12. CPU 丝印与 BOOT——F103 证伪、F407 证实；无 BOOT 跳线

- p1 三处丝印 **STM32F407ZGT6**（U1；引脚文本含 PA0-WKUP、PB8/SDIO_D4、PC6/I2S2_MCK 等 F407 命名）。SchDoc 的 "F103ZET6" 是旧符号误标，以 PDF 的 F407ZGT6 为准（这也意味着主频 168MHz、CCM RAM 等 F407 特性可用）。
- BOOT0(pin25) 仅 R113 10K 下拉 + RST/KEY（C45）复位电路；BOOT1=PB2。**未发现 BOOT0/BOOT1 选择跳线**——若需串口 ISP 需飞线，SWD 烧录不受影响。

---

## 对 B6 实物确认清单的影响

**可从实车清单划掉（PDF 已定）：**
- CPU 型号（STM32F407ZGT6，非 F103）；DS1 拨码位（PF12/PF14/PF13）；T5 上 PD4/PD5/PD6=7/9/11 脚；TJA1050=PD0/PD1；ADS1115 U17/U18 的 I2C 与通道分配；ACS712→AD5、LM358→AD6；SL1/SRD1/SRD2 完整驱动链；电源树结构。
- DR25 J1/J2 与 XT60 T1/T2 引脚-网络表已提齐（第 11 节），实车接线可直接照表，无需再抄板。

**仍需实物/实车确认：**
1. **T6（USART6 的 A_4/B_4）在实车是否插了外设**——决定 USART6 能否让给树莓派；同时确认 J1/J2 内 485 第 1/2 路总线（A_1/B_1、A_2/B_2）上实际挂了哪些设备，避免地址/负载冲突。
2. **NBREAK1/NBREAK2 的 CH3.96_2P 端子实车接法**：接的是刹车开关还是急停、常开/常闭、SW_IN 与 SRD1 触点的配合逻辑——PDF 只能看出"串入点"。
3. **SL1 断开的 MOTOR_1 回路实测**：确认 J2 12/13(MOTOR_1_2)、24/25(MOTOR_1_1) 与电机控制器 24V 进线的对应，以及电机控制器上电时序对 SL1 通断的依赖（PA5 断电是否导致控制器失电）。
4. **BOOT 无跳线** → 确认固件烧录走 SWD 即可，无影响；否则需飞线。
5. DR25 个别脚的双网络标签歧义（第 11 节带 \* 项）可用万用表通断 30 秒逐一敲定。

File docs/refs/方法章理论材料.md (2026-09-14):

# 方法章理论材料（论文第 4 章推导底稿）

> 用途：硕士论文第 4 章"感知与控制系统"的三块理论内容底稿。符号、推导链已按可答辩标准给出；**你消化后用自己的语言重写**，不要原文照抄（查重与答辩风险）。公式编号按"式(4-x)"预留。
> 对应代码：`pc/control.py`、`pc/perception.py`——每个结论都标注了代码出处，答辩问"实现了吗"可直接展示。

---

## 4.x.1 四轮差速底盘横向误差运动学模型

### 1. 运动学建模

四轮独立驱动、滑移转向（skid-steer）。取车体几何中心 O 为参考点，车体坐标系 {b}：x 轴向前，y 轴向左。左右侧轮速合成后，车体运动由线速度 v 与横摆角速度 ω 描述：

  v = (v_R + v_L) / 2            式(4-1)
  ω = (v_R − v_L) / W_eff        式(4-2)

其中 v_L、v_R 为左右侧轮速（m/s），W_eff 为等效轮距。因滑移转向存在轮侧偏与打滑，W_eff 大于几何轮距 W，需由试验标定（标定方法见第 5 章试验部分；代码对应 `DifferentialDrive`，vL/vR 合成即式(4-1)的逆运用）。

### 2. 横向误差动态

设期望路径为沿 x_s 方向的平行行线（行间除草的"路径"即草带中心线，视为局部直线）。定义横向误差 e 为车体中心到期望线的有符号距离（左偏为正），航向误差 ψ 为车体航向与期望方向之差。在 0.5 km/h 低速、采样周期 T=50-100 ms 条件下，采用自行车模型的一阶线性化：

  e(k+1) = e(k) + v·T·sin ψ(k)            式(4-3)
  ψ(k+1) = ψ(k) + ω(k)·T                  式(4-4)

小偏差时 sin ψ ≈ ψ。以轮速修正量 Δv = (v_R − v_L)/2 作为控制量，由式(4-2)，ψ̇ = 2Δv/W_eff，得开环传递关系：

  ė = v·ψ，   ψ̇ = (2/W_eff)·Δv           式(4-5)

### 3. PD 控制律与稳定性

控制律取 Δv = −(k_p·e + k_d·ė)。**建模口径（H4.6 定案 A）：以横向偏差 e 及其速率 ė 为二态，不引入独立航向状态；控制律只用 e、ė，模型与实现一致。**（代码 `DifferentialDrive.wheel_speeds` 实为 `dv = k_lat·e + k_heading·heading_err_rad`，主入口只传 e、航向项默认 0 → 当前等价纯比例，阻尼未生效。因 ė = v·ψ，`k_heading·ψ` 与 `k_d·ė` 是同一阻尼的两种参数化（k_heading = k_d·v）；两案已选后者并入代码（2026-09-14 审查合并）：`wheel_speeds(err_rate=…)` 显式加 k_d·ė，**k_d 默认 0（纯比例），台架整定前论文不得默认其已生效**。）

由式(4-3)~(4-5)（ė = v·ψ，ψ̇ = (2/W_eff)·Δv）对时间求导并代入控制律，消去中间变量 ψ：

  ë = v·ψ̇ = (2v/W_eff)·Δv = −(2v/W_eff)(k_p·e + k_d·ė)

即闭环误差动态为**二阶**：

  ë + (2v·k_d/W_eff)·ė + (2v·k_p/W_eff)·e = 0        式(4-6)

对应特征多项式 s² + (2v·k_d/W_eff)·s + (2v·k_p/W_eff)；二阶系统 Routh 判据即系数全正，故**稳定充要条件 k_p>0 且 k_d>0（v>0）**。（原稿"与航向通道联立得三阶特征多项式"系误：在本文假设下 ψ 只是中间变量、已被消去，无第三个独立状态，不额外引入执行器/滤波动态就是二阶。）

**工程含义（论文里值得写的一段）**：k_p↑→纠偏刚度↑、固有频率↑；k_d↑→阻尼↑、抑制超调；执行滞后（感知-控制-执行链路 ≈100 ms）等效引入纯迟延环节 e^(−τs)，使相位裕度随 τ 增大而下降——这就是田间"先低速后提速"调参的理论依据。答辩若问"为什么 P=1.5/s"，答：在 τ≈0.1 s、v=0.14 m/s 下按式(4-6)加纯迟延取 ≥30° 相位裕度反算所得，台架再整定。

### 4. 车速反馈与打滑

轮速由 TIM3 输入捕获测得（v̂ = c_per_pulse·f_pulse）。打滑率定义为 s = 1 − v̂_ground/v̂_wheel，田间用 GPS/标杆法标定 s，实际前馈使用 v̂·(1−s)。代码对应 0x10 状态帧的 speed 字段。

---

## 4.x.2 无线链路时延的前馈补偿推导

### 1. 时延来源

闭环环路：曝光→H.264 编码→Wi-Fi→PC 解码→推理→控制计算→UDP→桥接→串口→MCU→执行。第 i 帧的横向测量 e(t_i) 实际描述的是 τ_i 时刻之前的车体状态，τ_i ≈ τ_encode + τ_net + τ_infer（p50 实测见 `results/latency_log.csv`）。

### 2. 一阶补偿律

在 τ_i 内车体以近似匀速横移（低速+短时延假设），执行时刻的真实误差为：

  e_exec = e_meas + ė·τ_i            式(4-7)

其中 ė 为横向误差变化率，由有限差分加一阶低通得到（代码 `LatErrorRate`，α=0.3）：

  ė(k) = α·[e(k) − e(k−1)]/T + (1−α)·ė(k−1)     式(4-8)

式(4-7)本质是对时延的前馈校正：它不改变闭环特征方程，只把迟延环节的输入前移，因此**不引入稳定性风险**——这也是论文里"补偿放工程实现、不占创新点"论述的支撑。

### 3. 时延统计与失效保护

τ_i 逐帧测量，维护滚动窗口统计（代码 `LatencyCompensator`）：

  τ_used = median{τ_i}，窗口 N=100        式(4-9)

用中位数而非均值的原因：Wi-Fi 突发丢帧/重传产生重尾分布，均值被拉偏，中位数稳健。当 p95 超过阈值（50 ms 验收线）触发告警；帧丢失超过 500 ms 由看门狗强制 ESTOP（两级看门狗：MCU 端 + 树莓派桥接端，见第 3 章安全设计）。

### 4. 补偿收益的理论上界

若未补偿，等效迟延 τ 使相位裕度损失 ≈ 360°·f_c·τ（f_c 为闭环带宽）。取 f_c ≈ 1 Hz、τ ≈ 80 ms，损失约 29°——足以让原本 45° 裕度的系统接近临界。补偿后剩余误差为二阶小量 O(τ²·ë̈)，即由加加速度决定。**可试验验证的预言**：补偿开/关对比试验（第 5 章）中，关补偿时 RMS 横向偏差的恶化量应与 τ·v 成正比——数据若支持，该式即为讨论部分的定量论据。

---

## 4.x.3 IPM 投影误差分析

### 1. 单应变换的建立

设相机内参 K、畸变系数 k（标定自棋盘格，`calib_params.npz`）。地面 Z=0 平面上一点 P_g=(X,Y,0)，经外参 [R|t] 投影到像素 p = K[R|t]P_g。逆透视变换（IPM）即求地面平面到图像平面的单应矩阵 H：

  p̃ = H·(X, Y, 1)^T，  H = K·[r_1 r_2 t]       式(4-10)

工程实现用 4 组地面标记点（40/50 cm 间隔）由 `getPerspectiveTransform` 直接解 H（代码 `pc/perception.py` 的 IPM_SRC/IPM_DST，重标定工具 `pc/calib_ipm.py`）。

### 2. 误差源分解（论文表格素材）

| 误差源 | 量级估计 | 性质 | 对策 |
| --- | --- | --- | --- |
| 相机安装高度不确定性 δh | e_lat ≈ (Y/h)·δh | 系统性 | 装配后一次标定；0.9 m 机位、δh=5 mm、Y=2 m 时约 1.1 cm |
| 俯仰角不确定性 δθ | e_lat ≈ (Y²/(h))·δθ | 系统性、随距离二次增长 | 俯角刚性锁定；这也是远场控制带宽受限的物理原因 |
| 镜头畸变残差 | <2 px | 系统性 | 棋盘格全视场标定，先去畸变再 IPM |
| 地面不平（垄形） | 3-5 cm 起伏 | 随机 | 限深轮仿形只解决刀具侧；感知侧靠 Kalman 滤波抑制 |
| 标记点量取误差 σ_p | e_lat ≈ (Y/Z_ref)·σ_p | 随机 | 多组标记点最小二乘 |

### 3. 近场/远场双预视点的选择依据

中心线在鸟瞰图 y_far=180 px（远场）与 y_near=620 px（近场）两行取值（代码 `LOOKAHEAD_FAR_Y/NEAR_Y`）：

- 远场给底盘导航：预视距离长，等效加大系统阻尼，抑制航向噪声；
- 近场给中间刀：刀具在车前 0.3-0.5 m，近场点与刀具位置运动学一致，PID 无需附加坐标变换。

由式(4-10)误差分析知投影误差随 Y² 增长，因此**远场中心线天然比近场噪声大**——这就是为什么底盘中枢用 Kalman+PD（容忍噪声、优先平滑），而刀具用 PID+限幅（要求快速精确）。这个"一条中心线、两种滤波策略"的设计依据可直接写进 4.2 节。

### 4. 验证方法（第 5 章试验对应）

标记点重投影误差 ≤2 cm（v0.4 §5.6 验收线）。实测步骤：3 个标记点物理坐标 → IPM 反投影 → 欧氏误差统计均值与标准差。

---

## 4.x.4 展望素材：轻量分割模型的纸面对比（不实现，纯文献对比）

本项目选 DeepLabV3+(MobileNetV2) 的理由与嵌入式迁移路径的对比分析（论文"不足与展望"用）：

| 模型 | 参数量 | 现平台推理（GTX 1650，960×720） | 嵌入式前景 | 精度特点 |
| --- | --- | --- | --- | --- |
| DeepLabV3+ MobileNetV2（本项目） | ~5.8 M | ~300 ms（未优化） | TensorRT/NCNN 可压缩至 <50 ms | 高分辨率细节好，ASPP 多尺度感受野适合行墙连续边界 |
| BiSeNet V2 | ~9.8 M（轻量分支 ~0.6 M 激活） | ~80-120 ms | 官方提供 ARM 优化，速度/精度均衡出名 | 双分支设计专为实时，细节保持好 |
| ENet / ERFNet | 0.4-2 M | <50 ms | 嵌入式经典选择 | 极轻但边界精度下降明显 |

结论段逻辑：本项目 PC 集中算力架构下 DeepLabV3+ 的推理时延（300 ms）远超闭环需求（100 ms），但这不是瓶颈——瓶颈在无线链路与执行；若未来迁移车端自主（甩掉 PC），BiSeNet V2 是首选替代，其双分支结构与本项目"远场粗+近场精"的双预视点策略天然契合。**注意：表中数字为文献典型值，引用时需标注来源与测试条件，不可写成实测。**

## 答辩防身四问（预演）

1. **"滑移转向模型为什么不建全动力学？"**——0.5 km/h 惯性项可忽略，运动学模型+试验标定 W_eff 已覆盖主要非线性；动力学参数辨识的投入产出比不支持（对比试验数据优先）。
2. **"时延补偿为什么不用 Smith 预估器？"**——Smith 预估器需要被控对象精确模型，行间杂草环境下对象增益时变（土壤阻力）；式(4-7)的开环前馈不依赖模型精度，鲁棒性优先。
3. **"IPM 为什么不直接用 v̄=K[R|t] 解析解？"**——解析解依赖安装外参精确已知；地面 4 点单应把安装误差吸收进 H，标定流程简单且可田间重做。
4. **"边缘计算（RDK X5 等）能完成推理，为什么还用 PC？"**——三层递进：① PC 集中算力是 v0.4 需求基线里的显式决策：一期目标是固定算力变量、验证"双墙约束主动对行"方法本身；模型量化迁移（Horizon 工具链）是独立工作量，塞进秋季窗口会挤掉田间试验，属于资源分配而非技术依赖。② 真实无线链路是研究内容的一部分：时延分段测量、前馈补偿、开关对比试验都以链路存在为前提——边缘化会让第 4.2 节方法失去研究对象，论文变薄。③ 系统已按可演进设计：PC↔车端仅耦合 UDP 协议帧，感知模块独立封装，迁移 = 感知下沉 RDK（引脚/系统兼容，工具链成熟）+ 接口本地化，协议/状态机/控制/三级看门狗全部不动。收尾话术："论文测得的链路时延数据，恰恰论证了二期边缘化的必要性与方向；一期验证方法、二期迁移部署，是完整的规划而非欠账。"

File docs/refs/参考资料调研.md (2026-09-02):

# 参考资料调研（2026-09-02）

> 本项目定位：纯视觉芍药行间除草机器人——DeepLabV3+ 分割 + IPM 逆透视变换 + 双墙（作物行带）中心线提取 + 差速底盘导航 + 中间刀 PID 控制。以下三部分资料均围绕此定位提炼。

---

## 一、王硕论文（PDF 已解析）

**文件**：`C:\Users\22763\OneDrive\Desktop\论文\王硕080202机械电子工程20240605204550.pdf`（166 页）
**注意**：文件名虽为"机械电子工程"（硕士学科代码 080202），但正文页眉显示为**中国农业大学博士学位论文**，主题为"基于视觉导航的生菜田株间除草机器人"（生菜株间除草，非行间，但技术栈与本项目高度同源）。共 6 章，含完整目录书签。

### 1.1 论文主题与整体方案

- **总体方案**：四轮独立驱动独立转向（4WIS4WD）移动平台 + 凸轮摆杆式株间除草装置（后挂）+ 前置相机视觉导航。YOLOv5s（PP-LCNet 轻量化 + CBAM）识别生菜苗用于避苗；DeepLabv3+（改进）做垄语义分割，与 EXG/EXCg 植被指数特征融合后生成特征点，经距离滤波 + 改进 PROSAC 拟合导航线；控制端用 Kalman 滤波平滑导航参数，构建运动误差模型，设计带约束 MPC 并用模糊推理自适应调整权重矩阵；CoppeliaSim 仿真 + 田间试验验证。
- **关键结果**（摘要，p3–4）：
  - 改进 YOLOv5s 检测速度提升 91.12%，mAP 98.79%；
  - 导航线与人工标注真值平均重合度 0.93，拟合精度比霍夫变换 / 纯语义分割（SEM-MID）高 51.5% / 22.1%，25.5 FPS；
  - 田间导航横向偏差绝对平均值与 RMSE 均在 3 cm 以内；综合除草试验除草率 92.07%、伤苗率 2.51%。

### 1.2 对本项目可借鉴的方法、试验设计、指标定义

1. **视觉导航线提取链路**（第三章，p64–99，与本项目"DeepLabV3+ + IPM + 中心线"几乎同构）：
   - 其"垄语义分割 + EXCg 颜色特征融合 → 逐行检测苗带线 → 中心特征点 → 拟合导航线"的思路，可直接对应本项目的"双墙（两条作物行带）中心线"：它对**每一行单独检测苗带线再合成导航线**（p93），因此单行作物缺失时仍稳定——这正是双墙中心线法的核心论据，可在方法章节直接引用对比。
   - **距离滤波 + 改进 PROSAC 剔除离群中心点**（3.6 节，p83–89）：对处理垄边杂草产生的离群特征点非常实用，可作为本项目中心线拟合前的去噪手段或对比基线。
   - **杂草密度定量定义**（式 3-25，p94）：以逐行像素占比定义沟内杂草密度 ρF 和垄上杂草密度 ρR（0~1），本项目可照搬该定义做"不同杂草密度下中心线提取鲁棒性"试验。
   - **相机高度影响试验**（3.7.4，p95–96）：0.82/1.2/1.5 m 三档相机高度对导航线提取的影响，可作为本项目相机安装高度选型论证的参照试验设计。
2. **导航线拟合精度指标 CRDA**（3.7.1，p90，式 3-24）：作物行检测精度（Crop Row Detection Accuracy），逐行比较提取线与人工标注真值的横坐标偏差，归一化到 [0,1]。本项目"分割/中心线精度"试验可直接采用该指标（含其 IPM 调整系数），并配套 CRDA_avg、CRDA_std、FPS 三列表（表 3-5，p93）。
3. **导航控制性能指标体系**（5.2.1，p136–137）：以 RTK-GPS 10 Hz 记录位姿，每隔 5 m 采真值点最小二乘拟合导航线真值；定义横向/航向偏差的 **Max of AE、Mean of AE、RMSE、SD 四指标**（式 5-1）。本项目用 PID 而非 MPC，但指标体系、真值标定流程（垄中心重合行驶采点）可整体迁移；若无 RTK，可用高分辨率 RTK 或人工放样标杆替代并说明。
4. **除草作业指标定义**（5.3.1，p142–143，式 5-2）：除草率 RC=(1−NL/NC)×100%（明确"根部完全断裂/整体掩埋/根全部掀出"算成功）、伤苗率 RD=ND/NE×100%（"碰伤叶片即算伤苗"）、功耗 RW=ΣUI/t（30 Hz 采样电压电流）。另用**响应面分析法**优化凸轮转速、入土深度、前进速度三因素（5.3.1，p142–147）——本项目中间刀作业参数优化试验可套用同样框架。
5. **单因素场景化田间试验矩阵**（5.2.2–5.2.4，p137–141）：不同杂草密度、不同负载、不同前进速度、不同光照（晴天/阴天/暗光）、不同作物生长期分别做导航试验，每垄重复 3 次、出发区 2 m + 记录区 52 m + 停车区 2 m 的方案，可直接作为本项目试验章节的方案模板。
6. **绪论综述骨架**（1.2，p19–30）：除草机器人技术 → 视觉导航线提取 → 轨迹跟踪控制三段式综述，参考文献编号体系可作为本项目绪论文献池索引。

### 1.3 可引用到本项目论文的具体点（按章）

| 本项目章节 | 可引用内容 | 王硕论文页码 |
|---|---|---|
| 绪论·研究现状 | 除草机器人整机方案综述；视觉导航线提取方法分类（传统颜色/霍夫 vs 深度语义分割）；轨迹跟踪控制（PID/LQR/MPC）对比论证 | p19–30 |
| 绪论·技术路线 | "平台设计—感知—导航线—控制—田间试验"五段式技术路线图范式 | p31–32（图 1-14） |
| 方法·分割 | DeepLabv3+ 网络改进点、数据标注与训练设置、语义分割 + 颜色指数融合策略 | p72–83 |
| 方法·中心线 | 逐行苗带线检测合成导航线、距离滤波、PROSAC 离群抑制 | p83–89, p93 |
| 方法·IPM/相机 | 相机选型与标定流程、相机安装高度影响分析 | p64–67, p95–97 |
| 试验·分割/中心线 | CRDA 指标定义与六场景对比试验设计（含消融分析 3.7.5） | p90–99 |
| 试验·导航 | 偏差四指标（式 5-1）、RTK 真值标定流程、场景化试验矩阵 | p136–141 |
| 试验·除草 | 除草率/伤苗率/功耗定义（式 5-2）、响应面参数优化试验 | p142–148 |

---

## 二、李俊论文（PDF 已解析）

**文件**：`C:\Users\22763\OneDrive\Desktop\论文\玉米作物行间除草机器人行走控制方法与系统设计_李俊.pdf`（79 页，安徽农业大学硕士论文，用户已将原 CAJ 转为 PDF）
**主题**：玉米生长中期**行间**除草机器人——履带底盘 + 机器视觉导航线提取 + STM32 行走控制 + 末端旋转刀除草。这是与本项目"行间除草"定位最直接的国内先例，但技术路线为传统视觉，恰好构成本项目方法升级的对照。

### 2.1 论文主题与整体方案

- **整机**（第二章，p22–29）：履带式底盘（双电机**差速转向**，整机 1400×380×700 mm、80 kg、48 V 供电、作业速度 0.5–1.5 m/s），设计依据明确针对玉米行距 55–60 cm 限宽、限重（防土壤板结）、低重心；除草系统为电动伸缩杆升降 + 轮毂电机带动刀片。
- **视觉导航**（第三章，p30–52）：单目相机采玉米行间图像 → RGB 颜色分析 + 加权灰度化 + OTSU 最大类间方差二值化 → **CAANY 边缘检测**完成"玉米作物与蓝天背景"分割 → **RANSAC + 最小二乘**拟合导航线 → 经相机标定（Matlab Camera Calibration，25 张棋盘格图）由成像模型解算机器人**偏航角**作为唯一位姿输出。注意：其分割对象是"作物 vs 蓝天"（俯仰视角下作物高过相机、背景为天空），并非土壤背景下的作物/杂草分割，也未用 IPM。
- **行走控制**（第四章，p53–60）：STM32F1-V3 底层控制板（PWM 控 ZM-6615 无刷电机驱动器、降压电路、SBUS 遥控接收）+ Keil 下位机程序 + VC++/MFC 上位机导航软件（实时显示原图/OTSU 分割图/边缘图/导航线/偏航角与左偏-右偏-正常状态）。控制策略仅为**偏航角符号判断的开关式转向**（左偏右转、右偏左转），未见 PID/横向偏差闭环。
- **田间试验**（第五章，p61–71）：安徽农业大学玉米示范田（玉米株高约 70 cm、行间杂草高约 30 cm）。用 **MTi-G-710 GNSS/INS**（置于近重心处，四元数解算姿态）测行走稳定性，指标为**最大横摆角**与**行间除草率** η₁=(1−Q_H/Q_Z)×100%（式见 p64）。单因素试验（刀片转速 100–500 rpm、入土深度 10–30 mm、入土角度 30–75°）确定有效区间：转速 300–500 rpm、深度 20–30 mm、角度 30–60°（p64–66）；再用 Design-Expert 8.0 做**正交旋转组合试验**，拟合二次回归模型与 3D 响应曲面（p67–70），最优组合：刀片转速 409.95 rpm、入土深度 25.38 mm、入土角度 42.63°，除草率 84.52%、最大横摆角 1.9°（p71）。

### 2.2 可借鉴的方法与试验设计（含页码）

1. **"设计依据→技术参数表"写作范式**（2.1.1–2.1.2，p22–23）：从行距（55–60 cm）反推整机限宽、从防板结推限重、从稳定性推低重心，最后落到主要技术参数表。本项目芍药行间版可直接套用：由芍药行距/株高/垄形反推底盘尺寸与刀臂跨度。
2. **单相机标定 + 位姿解算推导链**（3.5.1–3.5.2，p47–51）：世界系→相机系→图像系→像素系的四级变换与畸变模型（式 3-24~3-29）、Matlab 标定操作步骤（25 张图、剔除大误差图、导出内外参）。本项目 IPM 一章可用更完整的现代表述引用此推导框架，并指出李俊仅输出偏航角、未解算横向偏差——本项目以 IPM + 双墙中心线同时输出**横向偏差与航向偏差**是明确改进。
3. **导航线拟合对照基线**（3.4，p44–46）：RANSAC + 最小二乘的传统拟合，可与王硕的 PROSAC、本项目的双墙中心线拟合同台对比，作为"传统方法在杂草密集/缺失场景下精度不足"的论据。
4. **开关式控制→PID 的对照论证**（4.3.2，p58）：其仅按偏航角符号做恒定转向修正、无偏差幅值与积分项，易在窄行间产生超调振荡；这为本项目"中间刀 + PID 连续控制"的必要性提供直接对照（可引用其流程图与控制逻辑作为现有不足）。
5. **试验指标与仪器方案**（5.2.3–5.2.4、5.3，p63–65）：GNSS/INS（MTi-G-710）测最大横摆角评价行走稳定性——本项目若不配 RTK，可仅用 IMU 横摆角 + 摄像机/标尺测横向偏差的组合；行间除草率公式 η₁=(1−除草后杂草数/除草前杂草数)×100% 可直接采用（本项目再补充伤苗率）。
6. **"单因素初选 + 正交旋转组合回归"两段式优化试验**（5.3–5.4，p64–71）：Design-Expert 因素水平编码表、二次多项式回归、交互效应 3D 响应曲面、Optimization 求最优组合的完整流程，是本项目中间刀作业参数（刀转速/入土深度/前进速度）优化试验的现成模板；评价指标同时含"除草率↑ + 最大横摆角↓"双目标，兼顾除草效果与行走稳定，值得本项目沿用。

### 2.3 与本项目"芍药行间"的差异点（论文"本研究必要性"论据）

| 维度 | 李俊（玉米行间） | 本项目（芍药行间） | 引申论据 |
|---|---|---|---|
| 作物与行距 | 玉米，行距 55–60 cm，株高约 70 cm（生长中期） | 芍药为多年生宿根作物，行距与冠幅、株高与玉米差异大，且生长早期冠层覆盖度低 | 行距/冠层结构不同 → 其限宽尺寸与"作物对蓝天"的俯仰成像假设不可直接迁移，需重新设计感知几何 |
| 感知背景 | 分割对象为"作物 vs **蓝天**"（利用高株作物与天空对比） | 芍药植株矮、相机视线背景主要是**土壤与杂草** | 蓝天对比法失效 → 必须采用 DeepLabV3+ 语义分割在土壤/杂草背景下区分作物带 |
| 导航线方法 | OTSU + CAANY 边缘 + RANSAC 单线拟合，仅输出偏航角 | DeepLabV3+ 分割 + IPM + 双墙中心线，同时输出横向偏差与航向偏差 | 传统方法在杂草密集、光照变化下鲁棒性不足（其 6.2 展望（1）p73 自认仅在理想天气光照下验证） |
| 底盘形态 | 履带式、80 kg、双电机差速 + SBUS **遥控为主** | 轮式差速底盘，自主导航 | 其展望（2）（p73）自述"尚未进行沿导航线的自主行走试验"——自主行间导航闭环正是本项目补齐的空白 |
| 控制方法 | 偏航角符号开关式转向 | PID 连续闭环（横向+航向双反馈） | 开关控制在窄行间易振荡，PID 引入幅值信息提高稳线精度 |
| 试验指标 | 除草率 + 最大横摆角（无伤苗率、无导航偏差统计） | 除草率 + 伤苗率 + 横向/航向偏差四指标 | 现有行间除草评价体系不完整，本项目建立更全面指标体系 |

### 2.4 可引用到本项目论文的具体点（按章）

- **本项目第 4 章（感知与控制）**：① 绪论/方法引入处引用其 OTSU+CAANY+RANSAC 传统链路（p30–46）作为对比方法；② 相机标定与坐标变换推导（式 3-24~3-29，p47–49）作为 IPM 推导的基础文献；③ 其"仅偏航角、无横向偏差、开关式转向"的局限（p51、p58）作为本项目双偏差 PID 闭环设计的动机；④ STM32 底层板 + 上位机的分架构与 SBUS/串口链路（p53–57）可对比引用说明本项目控制分层。
- **本项目第 5 章（试验）**：① 行间除草率公式与杂草计数规则（p64）；② MTi-G-710 测横摆角的稳定性评价方案（p63–64）；③ "单因素初选 → 正交旋转组合 → 回归优化"试验框架及因素水平编码/响应曲面呈现方式（p64–71）；④ 其最优组合（409.95 rpm / 25.38 mm / 42.63°，除草率 84.52%）可作为不同作物行间除草性能的对比参照数据。

---

## 三、GitHub 开源项目调研

### 3.1 geezacoleman/OpenWeedLocator（OWL）

- 悉尼大学团队的开源低成本除草喷洒装置，核心是"相机 + 树莓派 4 实时检测 + GPIO 继电器喷阀"的感知-执行闭环；早期为绿棕（green-on-brown）HSV 颜色检测，后扩展到基于 YOLO 的绿绿（green-on-green）识别。配套论文 Coleman et al., 2021（Computers and Electronics in Agriculture, 188, 106332）与 2022 Zenodo 设备论文。
- **田间标定流程**值得抄：手册明确要求手动固定相机曝光（防止自动曝光改变绿色判别阈值）、逐场景调节检测阈值与 ROI（最大/最小目标宽高、喷阀坐标窗口），并强调 GOG 模型必须用**同作物同生长期同田块**数据训练、用混淆矩阵逐类核查弱点。
- 对本项目借鉴：① 相机**手动曝光锁定**应写入本项目标定规程，否则分割模型在光照变化下漂移；② "ROI 窗口 + 阈值"的执行端安全约束思路可用于中间刀触发区域判定；③ 其 wiki 的"检测参数调优→混淆矩阵核查→田间复测"闭环可作为本项目试验 SOP 参考。文档结构（README + wiki 分层：硬件装配/软件/标定/故障排查）也值得本项目代码仓模仿。

### 3.2 PRBonn/cropandweed-dataset（CropAndWeed / CW）

- 波恩大学 Stachniss 组的多域作物-杂草数据集：先期 75 张大图（3456×5184）带像素级**茎、叶、作物/杂草**标注；后续扩展约 7000 张，覆盖 12 种作物/杂草、10 个语义类、多种土壤背景与生长期，标注以 24 倍降采样 PNG/JSON/COCO 提供，附上采样与匿名化工具。
- **许可**：数据仅限**非商业研究用途**（继承 EPFL CVLAB LaMFor 数据集许可），代码 MIT。写论文引用其论文（arXiv:2312.10548 等）。
- 对本项目借鉴：① 作为 DeepLabV3+ 的**预训练/预标注数据源**，再用小规模芍药田自采数据微调，缓解标注量不足；② 其"crop/weed/soil + stem/leaf"分层标注体系可作为本项目标注类别设计的模板（茎部标注对除草执行端定位有额外价值）；③ 多域（土壤/生长期/相机）采集策略可直接指导本项目数据集的多样性设计；④ 注意非商用约束不影响硕士论文使用，但若涉产业化需替换数据。

### 3.3 Zauberzeug/field_friend（feldfreund_devkit）与 Nindamani

- **Zauberzeug/field_friend**：商用除草机器人 Feldschärpe/Field Friend 的核心代码（feldfreund_devkit 为其 fork），Python/PyTorch on Jetson + ESP32 电机控制，基于自研 zeugma 框架的类 ROS 数据流。亮点是**监控与安全分层**：NiceGUI 主窗口聚合实时相机画面+检测框、状态图表、交互式地图与遥操作，感知模块与执行模块解耦、状态可观测。
- **Nindamani**（IROS 2020，Natarajan & Jeyaseelan）：AI 机械式除草机器人，YOLOv2-Tiny 检测 + "weed/non-weed"状态估计决策 + 四个独立旋转铲除草臂随车同步动作，高粱田实测。
- 对本项目借鉴：① field_friend 的**感知-执行解耦 + 状态监控面板**模式：本项目可将"分割结果/中心线偏差/刀盘状态/电池电压"做成上位机可视化，调试与田间排障效率大增；② 其 ESP32 下位机 + 上位机决策的分架构，对应本项目"工控机感知决策 + 底盘/刀盘 MCU 执行"的分层，可引用其接口划分思路；③ Nindamani 的"检测 → 状态估计（是否为目标）→ 机械执行同步"闭环提示：本项目中间刀启停应叠加作物/杂草判定门控（即使行间作业，也应防误伤偶入行的芍药植株），这一安全逻辑可在方法章单列一小节。

---

## 四、对本项目论文写作的直接引用建议（哪章引什么）

| 本项目章节 | 引用/借鉴对象 | 具体用法 |
|---|---|---|
| 绪论 1.x 国内外现状 | 王硕论文 1.2（p19–30）；OWL 论文（Coleman 2021）；Nindamani（IROS 2020） | 三条线综述：机械除草装备→视觉感知（颜色法/分割法对比）→导航与控制；OWL 作为低成本开源系统代表，Nindamani 作为检测-执行闭环代表 |
| 绪论 研究意义 | 王硕摘要背景段（p3）；李俊摘要（p4） | 机械除草改善土壤透气性、减少化学除草剂污染、株间/行间区域人工除草劳动强度大等表述可改写引用；李俊补充"行间杂草与作物争光争肥导致减产"（玉米中期场景） |
| 方法·图像分割 | 王硕 3.4（p72–81）；CW 数据集 | DeepLabV3+ 结构与改进依据；用 CW 预训练 + 芍药自采数据微调的数据策略，标注类别参照其 crop/weed/soil 分层 |
| 方法·分割对比基线 | 李俊 3.3–3.4（p30–46） | OTSU+CAANY+RANSAC 传统链路作为对比方法；其"作物 vs 蓝天"分割在矮秆芍药/土壤背景下的失效，论证 DeepLabV3+ 分割的必要性 |
| 方法·IPM 与相机 | 王硕 3.1（p64–67）、3.7.4（p95–97）；李俊 3.5.1（p47–49）；OWL 曝光标定 | 标定流程、相机高度对提取精度影响的试验设计；李俊的四级坐标变换与畸变模型（式 3-24~3-29）作 IPM 推导基础；手动曝光锁定的标定规程 |
| 方法·中心线提取 | 王硕 3.5–3.6（p81–89）；李俊 3.4（p44–46） | 双墙中心线拟合时引用其"逐行苗带线合成 + 离群点滤波（距离滤波/PROSAC）"作为去噪对比方法；李俊 RANSAC 单线拟合作传统基线 |
| 方法·导航控制 | 王硕 1.2.3（p28–30）、第四章；李俊 4.3.2（p58） | 绪论中用其 MPC/LQR/PID 对比论述论证本项目选 PID 的适用性；引用李俊"偏航角符号开关式转向、无横向偏差闭环"的局限作为本项目双偏差 PID 闭环的动机 |
| 方法·中心线提取 | 王硕 3.5–3.6（p81–89） | 双墙中心线拟合时引用其"逐行苗带线合成 + 离群点滤波（距离滤波/PROSAC）"作为去噪对比方法 |
| 方法·导航控制 | 王硕 1.2.3（p28–30）、第四章 | 绪论中用其 MPC/LQR/PID 对比论述论证本项目选 PID 的适用性（行间结构化走廊、双墙偏差直接反馈） |
| 方法·执行安全 | Nindamani 状态估计门控；field_friend 感知-执行解耦 | 中间刀启停的作物保护门控与模块化分层设计依据 |
| 试验·分割/中心线 | 王硕 3.7（p90–99） | CRDA 指标（式 3-24）、杂草密度定义（式 3-25）、六场景 + 消融的试验矩阵 |
| 试验·导航 | 王硕 5.2（p136–141） | 偏差四指标（Max/Mean of AE、RMSE、SD，式 5-1）、真值标定流程、每工况 3 次重复 |
| 试验·除草 | 王硕 5.3（p142–148）；李俊 5.3–5.4（p64–71） | 除草率/伤苗率定义（式 5-2）及李俊行间除草率公式（p64）、响应面/正交旋转组合优化作业参数、功耗统计方法；李俊最优组合（409.95 rpm、25.38 mm、42.63°，除草率 84.52%）作对比参照 |
| 试验·行走稳定性 | 李俊 5.2.3–5.2.4（p63–64） | MTi-G-710 GNSS/INS 测最大横摆角评价行走稳定性的方案（近重心安装、四元数姿态解算），可作本项目无 RTK 时稳定性指标的替代/补充方案 |
| 绪论·必要性论证 | 李俊 6.2 展望（p73） | 其自述"仅理想天气光照下验证""尚未进行沿导航线的自主行走试验"，直接支撑本项目"自主行间导航闭环 + 复杂光照鲁棒性"的研究必要性 |
| 数据与许可声明 | CW 数据集 LICENSE | 方法/试验章脚注注明数据集非商用许可及引用条目 |

---
*调研方法备注：王硕、李俊两篇论文均用 PyMuPDF 全文提取（含书签目录）；李俊论文原为 CAJ 格式，已由用户经 CAJViewer 转为 PDF 后解析。开源项目信息来自 GitHub 仓库/wiki 与公开论文检索。临时提取文件 `_wangshuo_raw.txt`、`_lijun_raw.txt` 保留于同目录备查，可删除。*

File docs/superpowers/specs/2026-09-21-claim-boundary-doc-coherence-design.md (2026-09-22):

# 主张边界与文档一致性修订（2026-09-21 开单，09-22 第二版）

> **本批做什么**：调整**验证主张、统计交付口径、准入判据与文档表述**。
> 不增加采集因素、不新增实验维度、不给工具加功能。
> （第一版自称"只改措辞、口径与事实登记"，被 09-22 审查指出不准确：删除按条件统计、
> 取消元数据记录、改变 S0 的触发作用，都属于**验证协议**调整而非文字润色。已改口。）
>
> 基线：qoder `b4e8e5d` 起的第二版；驱动来源为
> `D:\ai work\codex\docs\reviews\2026-09-22-two-specs-claim-boundary-review.md`。
> 该审查的"用户反馈后校准"一节是当前有效结论，本文件吸收其成立部分，
> 并逐条核过其对第一版的六项具体指错——**六项全部核实为真，其中五项是第一版我自己写错的**。

## 0. 作者决定与本版授权项（本版输入，共九项）

| # | 决定 | 来源 |
|---|---|---|
| 甲 | 不新增实验维度：不做跨田块泛化、季节或光照的分组对比实验，不额外跑田 | 09-21 |
| 2 | 时段、田块**都不逐图记录**；采集维度只作数据集覆盖说明 | 09-21 |
| 3 | V1 不按条件拆分报数 | 09-21 |
| 4 | 失视觉观测并进门 N 已有验收项，不新增第四项 | 09-21 |
| **5** | **场地只作地点声明**：论文只写"数据集与试验在哪片试验田完成"，其余不写；不记逐图田块。底线：地点层面成立 ≠ 逐图层面成立，不得顺势写"训练集与测试集同田块" | **09-22 作者定稿（取代本版初稿"同一采样区域"的绕写法）** |
| **6** | **V1 两类量分给两个数据集**：误差量→精选标注照片（有独立真值）；失败率与最长连续失效→3 段连续视频（保留顺序、不预筛）；双墙率在两边分开报 | **09-22 本版新增** |
| **7** | **秋季门 N 不等微调**：S0 升回门 N 的**可行性判据**，不过则按既有退路降为遥控采集 | **09-22 本版新增** |
| **8** | **物候拆两格**：当前叶在＝第一手现场观察；10 月中可用＝作者经验延伸判断；不用"3–4 年生 ⇒ 叶在"这条推理 | **09-22 作者复核** |
| **9** | **采集目录布局由 qoder 定案**（作者："跟试验和论文无关，你来决定"）：一个条件一个目录、一次跑一个目录、文件名保持 `{批次}_{日期}_{序号}` | **09-22 授权定案**，见 §6 E1 |

决定 5/6/7 纠正第一版三处错误，见 §2、§3、§5。决定 8 修正第二版矫枉过正的地方（把作者眼前的现场观察一并降成了"预期"）。决定 9 是作者授权我拍的，理由与代价见 §6 E1。

## 1. 现场事实与证据等级（第一版把两处抬高了）

| 编号 | 内容 | 等级 | 第一版的问题 |
|---|---|---|---|
| Hw-22 | 作者现场判断：目标田当前（9 月下旬）地上部叶片完整；**据当地多年种植经验，10 月中仍可用** | **第一手现场观察（当前状态）+ 作者经验延伸判断（10 月中）**；本次未做受控复核 | 两版各错一头：第一版写"物候前提由作物学依据**关闭**"，把推理链当成了证明；第二版降成"作者预期"，又把**已经在眼前的叶子**压成了猜测。作者复核："前者确实推不出后者，但叶子确实也在"——故拆成两格写：**当前可见性=现场观察；10 月中可用性=经验延伸判断**，且不使用"3–4 年生 ⇒ 叶在"这条推理 |
| Hw-23 | 作者报告现有权重在另一田块提线不佳，判断为小样本过拟合 | **口述经验；原因未经确认** | 第一版 A5 要求风险行写成"感知跨场地**不泛化（已知**，未量化）"。"已知"两字越界：机位、光照、生育期、采集条件都可能同时变了，不必研究，但不能排除 |

Hw-23 定稿措辞（替换第一版写法）：

> 作者报告现有权重在另一田块提线不佳，**原因尚未通过受控试验确认**。
> 本文不评价跨场地泛化；目标作业现场的可用性另行验证。

这一句同时保住三样东西：现场经验、研究边界、工程责任。

## 2. 改单 A · 主张与统计口径

### A1 — 场地限定语（决定 5）

作者定稿口径：**论文里只写"数据集与田间试验在哪片试验田完成"，其余不写。**
这一句把前两版的绕路都省了——它是**地点声明**，不是逐图归属证明；作者本人可核实，
不需要给每张照片贴地块标签。定稿措辞（写进第 2/3/5 章与本数据集描述）：

> 本研究的图像数据集与田间试验均完成于〔试验田名称/位置〕。数据集按连续采集批次
> 划分训练集、验证集与留出测试集；未逐图建立小区身份标签，不评价小区间差异。
> 结论限于该田块与本研究所开展的试验，不外推至其他田块。

⚠️ **一条底线，越过去这句声明就变成假话**：地点层面成立，不等于逐图层面成立。
秋采若确实跨了相邻若干片，**不得**顺势写"训练集与测试集来自同一田块"这种逐图层面的
话——那正是第二版"同场地条件下"被审查方击中的地方。要跨片就在同一句里写实
（"含相邻若干条垄，未逐垄标注"），主张范围不变。

前两版的自我消耗记在这里以免重犯：第一版写"限定为与训练数据同场地条件下"却又说
田块不记录（两句不能同时成立）；第二版改成"同一采样区域（含若干相邻田块，未逐图
建立地块身份标签）"——措辞合规但绕，把一个简单的地点声明写成了一句没人这么说的
免责声明。**地点 + 不外推**才是同行会写的形式。

### A2 — V1 两类量分开（决定 6），并把聚合定义清楚

"不按条件拆分"是**呈现方式**；"全集聚合"必须说是**哪个集**。第一版没定义，
是它被指出的真缺陷。定稿：

| 报什么 | 用哪个数据 | 为什么只能是它 |
|---|---|---|
| 横向误差：均值／标准差／95 分位／最大值 | 精选标注照片（人工独立标目标线） | 只有这里有**独立真值** |
| 失败率、最长连续失效 | 3 段连续视频（清单 §4 已列，≥30 s，明确不进训练集） | 只有这里**保留时间顺序**，且**未预筛**——无墙、遮挡、草密段都在内 |
| `status=dual` 双墙占比 | 两个集分开报，并注明照片集偏高 | 见下 |

四条必须写死的口径（不新增实验，属于评价有效性定义）：

1. **有符号还是绝对误差**：均值与 95 分位必须分别标明；不能用正负相抵的均值报精度。
2. **失败帧进分母**：误差统计只含"有独立真值且有有效预测"的帧；无法定义误差的帧
   记入失败率分母，**不得记 0，也不得悄悄剔除**。
3. **加权方式**：按帧还是按视频/批次等权，选一种写明（视频长度不等会改变聚合权重）。
4. **最长连续失效**只在保留时间顺序的独立视频上算，注明单位是帧还是秒及所用时基；
   **不得用散拍照片按文件名拼接失效时长**。

**分母悖论与它带来的采集侧后果（必须改采集清单）**：清单 §3 要求标注级照片
"画面内必须含两条完整芍药行墙"。在这类预筛样本上算出的失败率，含义只有
"**在两墙可见的精选样本中失败的比例**"。因此该集合**不负责**田间失败率——
这就是 A2 把失败率交给视频的原因。**副作用要如实说**：
照片集合上报告的双墙占比会**系统性偏高**，须与视频集合的占比并列。

**"dual 只代表算法说自己看到墙，不代表墙的位置对"** 这句也照写，
它由 A2 的分工自然消化：正确性由照片集真值负责，视频集只回答"能不能持续用"。

### A3 — 删掉两处第一版自己造出来的推论

- **"九格"推论撤销**：第一版称"真正对得上 240 的是光照×行况九格（240÷9≈27/格）"。
  撤销——原清单优先级是**非均衡**下限（主工况 ≥60、逆光中度 ≥30、阴天中度 ≥30、
  干净/茂密各 ≥15，名义和 150，且各项有重叠），既没列九格配额也不保证组合全覆盖，
  推不出九格。**第一版在撤回一个无依据推论之后，自己又写了一个同类错误。**
  改为：

  > 目标总量约 240 张，按既有优先级做非均衡覆盖，不要求四维全组合；
  > 视角为附带覆盖；**时段未记录，故不作"已覆盖"声明**。

  仍保留的一处订正：原句"四个维度全覆盖 + 每格 ≥15 张 + 合计 240 张"确实互斥
  （完整交叉为 3⁴=81 格），这句本身要改，但**不得**由此推出新配额。

- **"行业公认必须同田块"撤销**：第一版称台账 refs 第 92 行记的是"行业规矩：GOG
  必须用同作物同生长期同田块数据训练"，并据此说"换田块不保证是本领域公认属性"。
  审查方查了 OWL 现行官方文档：其训练建议是采集符合**具体现场条件**的图像
  （光照、土壤、生长期、作物），并允许使用适合条件的既有数据集——
  **不支持"必须同田块"这一概括**。我们那条本就是二手笔记里的概括，第一版又把它
  抬高成"公认属性"。删去"行业规矩／公认属性"这类话，**直接写本研究自己的数据与
  验证范围**，不借他人的未完成来给自己的范围选择背书。

- **李俊那条只保留它能支撑的部分**：核过原始 PDF 的是审查方——其展望确实自述
  "仅在理想天气/光照条件下做导航线提取""尚未进行沿提取导航线的自主行走试验"。
  它支撑的是**"同类工作会这样写局限"这一句式先例**（作者要求的"跟他们一致"落在这里），
  不支撑"本领域模型必须同田块训练"，也不支撑"本项目无需验证自主行走"。
  ⚠️ 本地 refs 记的页码 p73 与其核对结果（PDF 第 72 页／正文第 61 页）不一致，
  标为**待我方自查更正**，不照抄。

### A4 — v1.0 §8 假设行与 §9 风险行

- §8 第 231 行 `感知域差可修复（秋季微调后可用）` →
  改为 `现有权重在目标田的可用性：由 S0 判定（见 §4.2）；微调在其后，不作为秋季试跑前提`。
  **第一版没发现这行与 §7 排期构成硬矛盾**，见 §5。
- §9 第 243 行 R4 → `另一田块表现变差的原因未确认（Hw-23）；本文不评价跨场地泛化`，
  处置：按 A1 限定范围 + 按 §5 的 S0 判据决定秋季是 AUTO 还是遥控采集。

### A5 — 论文侧只登记，本批不动笔

开 **P15** 进 v1.0 §5 P 区清单：第 3 章 V1 小结与第 6 章展望需同步 A1/A2 的口径
（场地只作**地点声明**、两类量分两个数据集、不主张跨场地泛化）。
执行走 `chucao_prj/thesis_cau/` 例外授权，**手术式提交、每条独立 commit 并注明 P15**；
**本批只登记不执行**，避免文档批里混进未审的论文改动。

## 3. 改单 B · 台账与文献笔记

- Hw-22：按决定 8 **拆成两格**——"当前（9 月下旬）地上部叶片完整"记为**作者第一手
  现场观察**；"10 月中仍可用"记为**作者据当地多年经验的延伸判断**。
  两版各错一头：第一版写成"由作物学依据关闭"（把推理当证明），第二版整条降为"预期"
  （把眼前的现场观察也压成了猜测）。同时**删除**"3–4 年生"这条推理链，不保留。
- Hw-23：按 §1 定稿措辞改写（"原因尚未通过受控试验确认"）。
- **新增**：`docs/refs/参考资料调研.md` 第 92 行"必须用同作物同生长期同田块数据训练"
  加 **⚠️ 待核验** 标记并注明出处版本未记、与现行官方文档表述不一致。
  第一版的扫描范围漏掉了这个它直接引用的文件——**不改它，下一个人会从旧笔记
  把同一条推论重新引进来**。
- 李俊引文页码标注待自查更正（A3）。
- §4 修改记录表补两行（倒序最前）。

## 4. 改单 D · 门 N 验收：把软件约束与机械约束拆开（第一版混了）

第一版写的"抓线上帧 + 手推该轴不动双验收"混淆两件事：**撤使能后能否被外力推动，
取决于机构、制动与物理锁定，不能证明软件有没有发运动命令**。拆成两条分别验收：

- **软件约束**：在进入／退出空跑、旧命令残留、掉线恢复、急停复位四种场景下，
  **不产生被禁止的运动输出**（证据＝抓线上帧 + 固件输出状态）。
- **机械约束**：按实际采用的锁定方式确认刀梁与滑台状态（证据＝现场核对表 + 照片），
  判定标准（多大力、允许多大位移）**目前无依据**，本批不发明数字：登记进缺口清单 **B6"实物确认 5 项"类**（作者看一眼滑台与刀梁的锁止机构就能定），定为待补项而**非**待我想一个数。
- 双向都不许反推：不得仅凭"手推不动"判软件约束通过，
  也不得仅因"撤使能后可推动"就认定软件禁止运动失败。

**失视觉观测的措辞降级**（第一版夸了，zcode 上一轮连那句一起批了）：
`run_log.csv` 的 `frame_age_s / recv_timeouts / link_drops` 三列是**症状计数**，
只承诺区分"本地读超时／会话结束、无可用新帧、有图但感知不可用"三类现象；
**相机与网络的根因需车端记录佐证，无车端证据时标未知**。

门 N 该项验收要覆盖的四种场景（沿用已批的"不新增第四项"，仍属第一项的观测面）：
持续无帧；有帧但无可用墙；图像恢复；期间人工夺权。
每场分别核对：状态显示、发出的命令、MCU 输出、实际停止过程。阈值沿用经审查的
控制契约，不在本改单里另设数值。

## 5. 改单 C · S0 升回门 N 的可行性判据（决定 7；第一版降错了）

**为什么要升回来**：§7 把"标注、微调"排在 10 月中→11 月底，而门 N 自主沿行排在
10-05→10-15——**秋季试跑用不上微调后的模型**，只能用手上这套夏季权重；
而现有材料对它的评价正是"过分割 fg≈0.55、双墙不可用"（缺口清单 §C1、采集清单 §4 依据行）。
所以"现有权重能不能提线"不是工量参考，是**能不能跑 AUTO 的判据**。
第一版用"泛化不在研究范围"当作免拦的理由，属不相干推理。

定稿：

> S0 顺路收集可行性线索（不新增一趟），作门 N 试跑前的**输入有效性判据**：
> 现有权重提不出墙 → 秋季按既有退路降级为"遥控 + 感知在线记录 + C1 照采"，
> **不动搬运日、不等微调**；提得出来 → 按门 N 跑 AUTO。
> 进入受控试跑前另确认画面、标定与输入有效性，并验证失视觉时的实际停车行为。

**排期自洽性**：这么定之后，"试跑依赖微调"的暗含矛盾消失——因为试跑明确不依赖它。
§7 与 §8 相应两行同批改。**不得**一面在 §8 写"微调后可用"，一面把微调排在试跑之后。

S0 的产出仍**不含**按条件的分组结论（与决定 甲/2/3 一致）。

## 6. 改单 E · 一致性清理（第一版八处 + 本版新查出三处）

| # | 位置 | 改成 |
|---|---|---|
| E1 | README `--input data/autumn_data/raw` 会被自家嵌套拒绝挡住；双击 `启动预标注.bat` 走同一默认路径，同样被拒 | **布局由 qoder 定案（作者授权）**：维持采集清单的两层结构——一个条件一个目录、一次跑一个目录；文件名保持 `{批次}_{日期}_{序号}.jpg`。README 改成一次一目录的写法；`启动预标注.bat` 加"把条件文件夹拖到图标上即作为 --input"（脚本已转发 `%*`，只差无参时的处理），免得作者每次开命令行 |
| E2 | 图的家一会儿 `zcode/autumn_data/raw/`、一会儿 `qoder/data/autumn_data/` | 钉成 qoder 工作区内一个 |
| E3 | 采集清单第 11 行"手持模拟 ~0.9 m"与第 10 行 100 cm 打架 | 手持模拟也按 1.0 m；俯角留给 M11b |
| E4 | "四个维度全覆盖／每格≥15／合计240" 三句互斥 | 按 A3 的非均衡表述；**不引入九格配额** |
| E5 | 分组键文档"视频/地块/日期"（布局里没有地块这一级） | 统一为"一段连续拍摄（批次）"；代码 docstring 与帮助文本同改，不动行为 |
| E6 | 缺口清单第 36 行仍印着已撤回的"60 cm 需压行行走" | 改撤回后口径 + 挂 M14/M15 |
| E7 | ① 板数字全旧（mjpeg 4→15；Code/警告；E2③④ 未上板） | 按 09-21 实测更新 |
| E8 | README 第 218 行 "IPM 接线属 E2③" | **E2⑤**（我写错的编号） |
| **E9** | **v1.0 第 33 行 V2 那格"还差什么"仍写 `B1/B2/B5 未过`** | **本版新查出的残留**：B5 又挂回秋季 V2 前置，与门 N／门 F 拆分（秋季不含 B5）直接矛盾。这是 09-21 R2 该关掉而没关干净的一处，第一版改单也没列它 |
| **E10** | v1.0 第 217 行"标注、V1 **分层**评价" | 改"V1 总体评价（照片集误差量 + 视频集失效量）"。第一版只列了 32/45/234 行，**漏了这行与 33 行**，审查方"只列出部分替换位置"的批评成立 |
| **E12** | 采集清单 §4 三段视频的用途行现在只写"微调后的留出验证（回放测 status=dual 比例）" | A2 把**失败率与最长连续失效**交给了这三段视频，用途行要照写；并注明"拍摄时不挑画面——无墙、遮挡、草密段都要留在里面"，否则这个集被预筛过，失败率就失去意义。**这不是新增采集**：素材与趟次不变 |
| **E11** | "同一件事在两份文档各说一遍就是缺陷"（第一版 §2 纪律） | 收敛为：**禁止的是多个可独立修改、会互相冲突的权威源**；README 摘要、论文自包含的方法描述、不可变历史记录可保留并标来源。主方案本就要能独立读 |

## 7. 明确不做

不加田块维度、不加采集记录表、不做 leave-one-field-out、不做 EXIF 时段反推、
不设"不同条件下效果对比"小节、不为远地探针集再跑一趟、不改两个工具的**行为**
（E5 只动 docstring 与帮助文本）、不改论文正文（P15 只登记）、不开 E3。

若日后要证泛化，最小增量仍是：30–50 张位置真分开的图 + 只标目标线 + manifest 里
一个独立 held-out 名字。**记在此是为了下次不必重新想，不是为了现在做。**

## 8. 验证方式

1. **反向 grep**，范围 = 现行文档集（历史 spec 与 ch02 旧措辞保留原样）：
   `需压行行走`、`压过 4~5 行`、`全部可跨车迁移`、`五条件一条都不看`、
   `告警并退回逐图`、`低机位`、`四个维度全覆盖`、`九格`、`行业公认`、`同场地条件下`、
   `手推该轴不动`、`E2③ 未完项`——**只允许出现在"撤回／订正／举例"上下文**。
   命中数为零本身**不构成通过**，须能解释为何为零（09-21 二批教训）。
2. **改号／改名类改动**：全仓枚举新旧两种写法并打印命中处，逐处判定是"规范条目"
   还是"对别处的引用"（后者最危险：不报错，只会变成假话）。
3. **表格列数一致**；`分层` 一词逐处眼看，确认第 27／269 行"按验证环节分层"未被误删。
4. **主张自检**：V1 每个量都能回答"在哪个数据上算、分母是谁、有符号还是绝对"；
   §2 存在"本文不主张"清单；R4 不再用"未验证"这类含糊说法；
   **Hw-22/Hw-23 的等级栏与正文主张强度一致**。
5. **范围核对不能只看测试数**：本改单自己**不加断言**，执行后 `pytest -q` 应与执行前的
   当前基线**同数**（09-22 写作时基线 **148**：135 → 文档不变量检查器 +7 = 142 → 门 N 状态
   记录器 `tests/test_bench_status.py` +6 = 148；两次上涨都要能指到具体提交，指不到即越界）。
   同时必须核对
   ① 代码 diff 仅 docstring/帮助文本 ② 断言未增删 ③ 运行环境与被审版本一致。
   **测试通过或总数相同，都不验证文献原句、测量口径或因果结论。**
6. **排期自洽**：§7 与 §8 中不存在"秋季 AUTO 依赖微调"与"微调排在秋季试跑之后"并存。

## 9. 谁做、什么时候

qoder 单批完成（纯文档 + 两处代码注释），HEAD 报作者转 zcode。
**不占作者下田时间**；作者侧仍只有 v1.0 §4.2 那几项，其中 S0 已按 §5 升回判据，
它的结论**能替你省掉一次白搬车**——这是它比第一版值钱的地方。

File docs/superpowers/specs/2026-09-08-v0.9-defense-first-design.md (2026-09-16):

# 纯视觉芍药行间除草机器人 · 硕士论文实施方案 v0.9（答辩优先 · 评审后修订版）

> ⚠️ **本文件已被取代（2026-09-16）**：现行方案是 `2026-09-16-v1.0-system-validation-design.md`。
> 保留本文件只为追溯决策史。实质变更：主贡献由"主动对行方法"改为**整机设计与田间系统验证**（作者选定 C 路线、导师口径已确认）；
> 秋季由"非头条试跑"升格为**有完整记录的预实验**并钉死范围（只测自主沿行 + 偏差/失效，刀控推春季）；
> §8 创新点 1 与 §9 降级包按 v1.0 §8 重写；IPM 误差式（T4）与时延补偿的理论地位按 v1.0 Δ5 降级。

> 状态：v0.9 草案，待作者 + 导师书面确认（见 §13）
> 日期：2026-09-08
> 版本：v0.9。基于 v0.8 经两份外部评审（Codex 评 6.5/10「有条件通过」、ZCode 对照 v0.7 复核）后修订；并确认运动学走**路线甲（真做 4WS 自主转向）**。
> 性质：中国农业大学硕士学位论文样机项目。作者：杨顶浩；导师：刘星星。
> 北极星：**答辩 2027-05、送审 2027-04 中旬**（真正的数据死线）。田间除草季春→秋，但**头条田间试验目前只有 2027 年 2–3 月这一趟，且尚未确认为已成立前提**（§6 前提验证门）。
> 说明：本文件仅**方案**，不含代码。zcode 的代码/固件/文档/台账作为继承资产（§11），实施阶段才复制进本 qoder 工作区。

---

## 0. 一句话总纲

以 v0.8 的"答辩倒排 + 感知数据第一关键路径 + 论文地基纠错"为骨架，吸收 Codex 的"工程纪律"（四运行模式结构性隔离、验证阶梯、准入门、证据矩阵、未实测不得称已实现），把 4WS 台架工作前移到 11–12 月、秋季加非头条试跑、春季班车降级为外部依赖，并新增**前提验证门 / 接口验收表 / 预注册实验设计 / 最小可答辩降级包**四块，压掉所有隐含假设。

---

## 1. v0.8 → v0.9 变更摘要（评审驱动）

| # | 变更 | 来源 |
|---|---|---|
| Δ1 | §3.1 运动学由"定论=4WS"降级为**"硬件为真、模型经台架验证后冻结"**；工作包由"重写 4WS 控制器"更正为"**已有 `Ackermann4WS`，缺口在传链/轮序/标定/闭环**" | Codex #1/#2、ZCode #2 |
| Δ2 | **4WS 台架侧前移 11–12 月**（撤锁/映射/寄存器核对/转角标定），不压 1 月 | ZCode #2 |
| Δ3 | "双轨互不致命"更正为**"并行推进 + M→A 关键接口串行汇合 + 交付契约"** | Codex #3 |
| Δ4 | 2027-02–03 田间窗口由"计划前提"降为**P0 外部依赖**，须锁定替代地块/人工验证区 | Codex #4 |
| Δ5 | 秋季加 **1–2 趟非头条试跑**（把"首次整机下田"移出班车窗口） | ZCode #1 |
| Δ6 | 实验统计：弃"全 ANOVA"，改**预注册 + 区组/配对 + 比例指标二项 GLMM** | Codex #5 |
| Δ7 | 指标阈值补**验收定义表**（来源/协议/分母/阈值/置信/失败决策） | Codex #6 |
| Δ8 | "RMS 恶化 ∝ τ·v" 降为**预注册可伪假设** | Codex #7 |
| Δ9 | 创新点 2 重定位（4WS 作系统贡献，方法新颖性显式论证） | Codex #8、Q3 |
| Δ10 | 新增**最小可答辩降级包** | Codex #9、Q2 |
| Δ11 | 新增硬伤：**中间刀执行器"步进"→"伺服"**纠错（ch02/ch04 + §4.x.1） | 本轮自查 |
| Δ12 | 继承补收 v0.7 §13 引脚清单、§11.4 坑清单 | ZCode #3 |

---

## 2. 目标与完成定义（吸收 Codex §1）

目标 = 完成硕士毕业所需的**工程样机 + 验证证据 + 田间数据 + 论文 + 答辩材料**，而非仅软件模块。**硬纪律：未完成硬件测试的功能不得在论文/PPT/状态表中描述为"已实现/已验证"；目标指标与实测结果必须分列。** "完成"须同时满足：离线与集成测试通过；固件可复现编译且关键安全路径有验证记录；台架通信/模式切换/失联/急停/刀联锁通过；带动力实车准入条件满足；田间实验产生可追溯原始数据与统计；论文结论可溯源到代码版本/配置/实验记录；PPT 与论文与实车状态一致。

---

## 3. 论文地基一致性硬伤（定稿）

### 3.1 转向——**路线甲（细化）：前轮 Ackermann 转向 + 后轮回正；转向不作创新点**（R4 已定）
- **事实层次（逐条核实，不再越界）**：
  - 硬件为真：`main.c:521–530` 向四个 Modbus 地址各发 `send_angle`；台账 Hw-13 🟢"转向伺服在车、已接线、MANUAL 遥控可用"；Hw-11 记录伺服走 UART4/Modbus-RTU，`send_angle`=绝对位置寄存器 0x0016。
  - 模型**未**验证：Hw-11 🟡 寄存器表未核对；转角零位/回差/响应速度/负载/同步误差未标定。
  - **现状**：`main.c:519` 在 AUTO 把 `angle[0..3]=0` 锁死、只走差速——**当前 AUTO 根本没使用四轮转向**。
- **定论（R4 已定，2026-09-14）**：作业控制模式取 **① 前轮 Ackermann 转向 + 后轮回正**——平台硬件具备四轮独立转向（如实描述，绝不再写"无转向机构"），但本研究作业**不引入后轮反相/蟹行**，**转向降为"实现细节"、不作创新点、第 4 章不展开推导**（对齐李俊/王硕等行走控制类学位论文：贡献在"视觉导航线→轨迹跟踪→主动对刀"，转向只是执行手段）。运动学模型仍**经实物轮序/零位/回差/响应/负载台架验证后冻结**。
- **R4 几何 bug 与消解**：现 `nav_control.py:146-149` 让后轮反相偏转，与前轮不共 ICC（复审 09-14 数值验证：左右两组 ICC 相差 0.4m=轮距，"四轮绕同一 ICC"不成立）。**改为后轮角恒 0（前轮-only Ackermann）即由构造消除该矛盾**——前轮按 `atan(L/(R∓tf/2))`、轮速按各轮到 ICC 半径比例分配。补三条单测：**左右镜像、δ→0 直行极限、刚体速度一致性**。
- **工作包（更正后）**：控制器 `Ackermann4WS` 已存在，缺口是：① 感知→控制器接口完整性；② PC 帧传到 STM32 `angle[4]` 的通路；③ 四轮编号/符号/单位映射；④ 撤 `main.c:519` 锁死、AUTO 改接前轮转向指令（后轮置 0）；⑤ 转向限幅/变化率/失效安全；⑥ 台架标定（零位/回差/寄存器）与闭环验证；⑦ **前轮-only 几何改写 + 上述三测**。**不是"从差速重写控制器"，也不做完整 4WS 反相。**
- **对开题的显式调整声明**：开题承诺"四个转向轮期望偏角"；本研究采用**前轮转向 + 后轮回正**，四轮协同小半径/原地转向作为**平台能力演示/展望**，非作业控制律必做项——与"林下→大田"同列为显式调整。
- **排期**：①–④⑥的台架侧**前移 11–12 月**（此时舵机 manual 可用、控制器已在）；⑤ 闭环验证留春季。
- **退路（诚实兜底，须数据触发）**：若 11–12 月台架证明转向舵机滞后/回差不达自主对行要求 → 转路线乙（锁直+差速作业）并**如实写"车具备四轮转向、本模式选择不用并给理由"**；**任何情况下都不得再出现"没有转向机构/纯滑移"表述**。
- **连带必改（不等定稿）**：`thesis_cau/ch02_draft` §移动平台"转向不设转向机构"、`ch04_draft` §滑移转向运动学、`决策依据说明.md` D8、`开题`口径差异，全部按 4WS 重写。**注意 `chucao_prj` 为只读原仓，此项在迁移后的 qoder 工作副本内改，或单列任务，禁止直接改只读仓。**

### 3.2 场景——大田（已定：改大田 + 重定理论#1）
理论意义#1 由"林下破碎斑驳光影(Dappled Light)"重述为"**非结构化大田多变光照（顺/逆/阴）与跨季物候域偏移下作物行墙鲁棒提取**"；秋季光照矩阵（D3）为兑现形式；"林下→大田"作**显式开题调整声明**；开题"避障/绕树"降为展望。

### 3.3 指标口径
删与"只行间、不做单株识别/避苗"矛盾的 `ch02` 表 2-1"幼苗识别≥92% / 避苗损伤≤3%"。统一为可兑现口径（见 §7 验收定义表）：横向偏差、中间刀对行偏差、行间除草率、药苗损伤率、航向偏角标准差、时延 p95。

### 3.4【新增】中间刀执行器：步进 → 伺服
台账 Hw-7/Hw-12 实车确认中间刀微调为 **400W/48V 直流伺服（与转向同型，位置模式收 PUL/DIR 或 Modbus）**，非 NEMA17 步进。`ch02` §除草装置、`ch04` §中间刀 PID、`方法章理论材料 §4.x.1` 的"步进电机 / 8mm÷(200×细分) 分辨率"推导按伺服 + 电子齿轮重标；对比试验的重复定位验收线不变。

---

## 4. 双轨结构（含 M→A 交付契约）

- **M 轨（方法与离线证据）**：域差修复与感知鲁棒、导航线三方对比（Hough / 朴素 LSQ / 行投票裁剪，对齐开题 2.3）、双墙消融、IPM 独立点验证、时延前馈离线推导。**产出 = 稳定可交付的导航线输出**。
- **A 轨（系统与田间，AUTO 必做）**：链路 B8、台架安全 B5、4WS 台架→闭环、田间三组对比、答辩演示。
- **关系（更正）**：两轨**并行推进**，但在"感知→控制"这一**关键接口串行汇合**。M→A 交付契约：M 轨须产出满足 §7 接口验收表（导航线连续性、横向偏差可解算率、双墙有效判定口径）的输出，A 轨 AUTO/主动刀/田间对比才有输入；**M 轨不达标，A 轨田间数据无法产生**——故 M 轨（尤其感知）是关键路径头部，不是并行无关轨。
- 半自主（人遥控走直线）**仅作上 AUTO 前内部 bring-up，论文不写、不作数据来源**。

---

## 5. 关键路径与倒排里程碑（绝对日期；含两处前移/降级）

| 时间 | 轨 | 里程碑 | 验收门槛 |
|---|---|---|---|
| **现在–10 月中** | M | **C1 秋采**（图像+新视频+光照矩阵+低机位标定顺带） | 清单 100%，入 `autumn_data/raw/` |
| 10 月中–11 月底 | M | C2 标注微调；导航线三方对比/双墙消融/IPM 独立验证 | 秋季域 status=有效双墙判定达标（口径见 §7）、mIoU 见 §7；对比表成型 |
| 11–12 月 | A | 链路 B8、烧录 B1、协议对拍 B2、接线 B3、采购/E2 到货、RDK 适配(P1-4)、B6 实物、继电器板判读 | 链路通、状态帧 20Hz、坏帧静默丢弃 |
| **11–12 月（前移）** | A | **4WS 台架侧**：撤 `angle=0`、指令映射、寄存器核对、四轮转角零位/回差标定 | 台架可四轮独立转向到位、回差/滞后量化入台账 |
| 2026-12–2027-2 | 写作 | 第 2 章(决策记录修正版) + 第 4 章(4WS 重写) + 第 3 章秋季域补指标 | 方法章成稿、图表齐 |
| **2027 1 月底** | A | **4WS 闭环联调 + 台架安全五项 B5**，系统"可下田"冻结 | AUTO 用四轮转向稳定跟踪、联锁实测、无 AUTO 侧 P0 |
| 2027 2–3 月（**外部依赖，见 §6**） | 田间 | **D16 三组对比 + 答辩演示**；时延实测 F3；**秋季若已能下田则先跑 1–2 趟非头条试跑** | 头条数据到手，3 月底封版 |
| 2027 4 月初 | 写作 | 第 5 章结果 + 全文合成 + 摘要 | **送审** |

关键路径：**C1 秋采 → 域差修复 → 4WS（台架前移+闭环）→ 春季田间班车 → 送审。**

---

## 6.【新增块】前提验证门（未验证的假设，不得当计划前提）

| 假设 | 当前证据 | 验证方式 | 冻结判据 | 未过的决策 |
|---|---|---|---|---|
| 春季 2027-02–03 田块可下田、芍药有可见行墙、草密度足够 | **无**（§13 待确认） | 田块负责人书面确认 + 生育期/冠层预判 | 准入+物候双确认 | 启用**替代地块或人工构造行间验证区**；仍不足则触发 §9 降级包 |
| 4WS 舵机满足自主对行的精度/滞后 | 硬件在、manual 可用；闭环未测 | 11–12 月台架转角阶跃/回差/负载试验 | 到位误差与滞后满足 §7 判据 | 转路线乙（诚实写"锁直+差速"），§3.1 退路 |
| 感知域差可修复（秋季微调后 avi 可用） | 夏季域 mIoU0.72、avi 上双墙提不出 | C2 后用留出 avi 回放 | 有效双墙帧占比达 §7 阈值 | 启用经典 OpenCV 行线兜底通道作数据源 |
| 无线链路满足实时 | 未实测 | B8 120m 打流 | 丢包/时延达 §7 | CPE 定向/换更高功率型号 |
| MCU 能读到轮角反馈（4WS 转向失效检测的信号源） | 台账 Hw-11：原车外部轮角采样链退役、伺服内部闭环 | 核对 `uart4.c`/驱动器能否读回实际角度寄存器 | 能稳定读回实际转角 | 去掉"反馈式"失效检测，改软件估计（指令-模型一致度）或降为展望 |

---

## 7.【新增块】接口与验收定义表（消除"拍脑袋阈值"）

**M→A 接口契约**：感知模块向控制层暴露 `{导航线(远/近场点序列), 横向偏差 e(m), 横向速率 ė, 双墙有效标志, 置信度, 帧时间戳}`；更新率、坐标系(IPM 物理坐标)、缺失语义（None/降级）须固定并测试。

| 指标 | 分母/口径（写死） | 阈值 | 来源 | 失败决策 |
|---|---|---|---|---|
| 有效双墙帧占比(dual) | 分母=**全部作业有效帧**（非人工挑帧）；分子=双墙均通过面积/长宽比与连续性判定的帧 | ≥80%（**待用真实帧标定金标准后确认，先作目标值**） | C2 留出 avi 回放 | 降速/换机位/兜底通道 |
| mIoU | 验证集，二分类前景/背景，秋季域 | 见 §13（暂 0.75 为**目标非实测**） | 训练日志 | 补采/损失加权/难例挖掘 |
| 底盘横向偏差 | 20 m 直线，外置基准实测，均值±标准差 | ≤±5 cm | 田间 | 调参/降速 |
| 中间刀对行偏差 | 近场中心线-刀具 | ≤±2 cm | 田间/台架 | 预瞄/前馈 |
| 药苗损伤率 | 抽样样方逐株判定，分母=经过株数 | **≤1%（目标）/ ≤3%（外层界），待导师定 §13** | 田间 | — |
| 链路时延 p95（**控制帧**） | NAV/HEARTBEAT 往返 RTT 或 MCU 回显；**不是** `main.py` 的感知 latency 列（那列只包感知处理）；丢包率分母=已发帧数，非 rx_good/rx_bad | <50 ms | B8 打流（10 min） | CPE/朝向 |

（每格测量协议、置信区间与是否可再生在 writing-plans 落地为可执行记录。）

---

## 8. 创新点、证据映射与预注册实验设计【新增块】

**创新点（重定位）**：
- **创新点 1｜四行三带并行机械除草 + 中间刀视觉主动对行方法**——方法贡献，证据=导航线精度 + 主动 vs 固定刀田间对比。
- **创新点 2（重定位）**：把"纯视觉 + 车-PC 分布式 + 多级安全联锁"作为**系统贡献**陈述；**转向（含四轮硬件）明确降为实现细节，不作创新点、不展开推导**（见 §3.1）；**仅当对某类已有系统显式论证"新增了何种方法、为何非常规集成"后，才升格为科学创新点**（§13 待导师确认新颖性口径，Q3）。
- **后备点 3｜时延前馈补偿**作第 4 章方法贡献。

**预注册实验设计（采集前冻结，owner=导师/懂农试统计者，§13 Q4）**：
- 明确：每趟是否独立试验单位；跨田垄/日期/光照/草密度的**随机区组**或**配对**结构；处理顺序**随机化**；主效应/交互/协变量；多重比较校正。
- **比例指标（除草率、伤苗率）用二项 GLM/GLMM**，不套普通 ANOVA；连续指标（偏差/时延）用（线性）混合模型或区组 ANOVA；n=3（刀具组）仅作品质/趋势，**不作正态性/方差齐性充分检验**，核心组保证重复数。
- **预注册假设（允许被数据推翻）**："时延前馈补偿使横向 RMS 偏差的恶化量随 τ·v 单调增"为**待检验假设**，非既定结论；数据不支持则如实报告并写入讨论。
- 原始数据只追加不覆盖；清洗与排除规则留痕；论文/PPT/状态表从**同一证据矩阵**（主张→指标→实验编号→原始文件→脚本→图表→提交）取数。

---

## 9.【新增块】最小可答辩降级包（Plan B，须导师书面确认边界）

若春季全自主/AUTO 田间失败，论文仍可成立的最低证据包（**边界待 §13 Q2 确认，先起草**）：
- 可依赖：感知方法与导航线三方对比（M 轨，含秋季域）；4WS 台架/受控转向与对行验证（B 台架侧）；除草机构对比（鸭掌铲 vs 弹齿，可台架/短田）；安全联锁台架实测。
- **必须删除的表述**：任何"田间全自主作业已验证"的头条结论降级为"台架/受控验证 + 展望"。
- 是否仍满足培养/送审要求 = 由导师据最低包判定；本包目的是**防"一次田间失败摧毁全部交付"**，非放弃 AUTO 主目标。

---

## 10. 验证体系（吸收 Codex §7，未过不进下一级）

静态检查（路径/协议字段/固件符号/危险调用）→ 单元（协议/预处理/控制边界/安全状态机）→ 集成（录制图→安全命令、UDP→串口、STATUS 回传）→ 故障注入（丢帧/乱序/延迟/CRC 错/来源伪造/视觉空）→ HIL 台架（MCU/继电器/限位/急停/模式）→ 架空轮低速 → 无刀/提刀空载 → 受控短距入土 → 田间重复实验。**replay/simulation 结构性封锁实车发送通道（非配置约定）**；每级带日期/提交/配置/操作者/结果记录。

---

## 11. 继承清单（实施阶段执行，不复制不丢项）

- 继承 zcode：`common/network/pc/vehicle/tools/firmware/tests/docs` + `thesis_cau` 草稿。
- **必收 v0.7 遗留**：§13 引脚级改装清单、§11.4 坑清单（权重两套、`calib_params.npz` 的 mapx/mapy 被忽略等）、参数差异台账（Hw/Fw/Pc 全部 🔴/🟡 项）。
- 本 qoder 成唯一开发区；`chucao_prj`/`zcode` 转历史只读。§3.1/§3.4 的 ch02/ch04 文本纠错在**迁移后 qoder 工作副本**做，不改只读原仓。
- 方案批准后经 writing-plans 拆任务，首批＝感知数据抢救 + 4WS 台架前移 + §3 硬伤文本修正。

---

## 12. 风险台账（答辩优先）

| ID | 风险 | 影响 | 缓解 |
|---|---|---|---|
| R1 | 春季班车是**未确认外部依赖**（§6） | 头条数据落空 | 立即确认田块；锁替代地块/验证区；秋季非头条试跑预热；§9 降级包 |
| R2 | 感知域差未解 | 第 5 章无稳定导航线 | 秋季 C1/C2 优先；OpenCV 行线兜底 |
| R3 | 4WS 台架不达标（滞后/回差） | AUTO 自主转向不成立 | 台架前移 11–12 月早暴露；退路乙诚实写（§3.1） |
| R4 | 硬件在场依赖（继电器板/RDK/田块） | A 轨阻塞 | 采购/实物本周并行；M 轨不受阻先做 |
| R5 | 开题↔论文一致性（4WS/林下/步进/指标） | 答辩穿帮 | §3 四条显式改 + 调整声明 |
| R6 | 统计设计无人冻结 | 数据拿到也不能解释 | §13 Q4 指定 owner，采集前签 |
| R7 | 送审前占位/图表未兑现 | 不能送审 | 4 月初封版为硬门，逐 `<待补充>` 挂 owner |

---

## 13. 待作者/导师**书面**确认（v0.9 已按推荐默认起草）

1. **Q2 最小可答辩降级包边界**（§9）——导师书面认可。
2. **Q3 创新点 2 新颖性口径**（§8）——按系统贡献 or 提出并验证新 4WS 控制方法。
3. **Q4 预注册实验设计冻结 owner**（§8）——导师或农试统计人员。
4. **药苗损伤率验收线** ≤1% 还是 ≤3%（§7）。
5. **春季 2027-02–03 田块 + 物候 + 现场准入**（§6，升格计划前提的唯一钥匙）。
6. **送审确切日**（暂 2027-04 中旬）。

---

## 14. 下一步

§13 关键项（至少 1、4、5）落定后进入 writing-plans，输出带依赖与周检查点的可执行计划；首批实现任务＝感知抢救 + 4WS 台架前移 + 文本纠错 + 代码复制与 §11 台账收纳。

---

## 15. 设计自审（v0.9）

无未决占位（外部未完成项均定义为 §6 准入条件或 §13 待确认，非 TBD）；§3 与 §8/§10/§12 一致（4WS 定为甲+退路、模型待冻结）；创新点↔证据↔试验设计三向对齐；范围收敛于毕业样机，不引入无关重构；"完成"以可检查的工程/实验/文档条件界定，不以代码存在代替验证。

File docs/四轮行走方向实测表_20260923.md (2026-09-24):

# 四轮行走方向实测表（2026-09-23 建）

> **这张表决定一件事：固件里该翻哪一个轮的方向引脚。** 上一版我按"整个前轴镜像"翻了 LF+RF，那个观察被作者更正掉了，补丁已撤回（宏=0）。**表填完之前不再改固件。**

## 0. 先填这两行，否则表没法解读

| 项 | 填 |
|---|---|
| 板上这份 hex 是哪一次编译的（`car_control.c` **第 8 行**写的是 0 还是 1） | |
| 测的时候车是吊轮还是落地 | |

今天出过两份 hex，行为不同，**不记这一行整张表都无法归因**：

- **13:36** = 宏 1 = 前轴两轮（LF、RF）方向引脚已翻转
- **15:31** = 宏 0 = 厂商原样（当前仓库里就是这份）

## 1. 表：四轮贴标签，逐格填「前 / 后 / 不转」

**轮名按你眼睛看着车身定的写，不要用代码里的名字**——"代码下标 ↔ 物理车轮"正是待证项之一，用代码名填等于把结论当前提用。

「前」= 相对车头朝前滚；「后」= 朝后滚；「不转」= 完全不动。

| 轮（贴标签） | 纵向 + 前进档 | 纵向 + 后退档 | 横向档 | 备注（轮面朝向对不对） |
|---|---|---|---|---|
| 左前 | | | | |
| 右前 | | | | |
| 左后 | | | | |
| 右后 | | | | |

**后退档怎么给**：油门杆只给非负速度，**往回拉不倒车**。后退是遥控器上另一个开关（通道 3，见 `docs/遥控器键位通道映射表_20260923.md`）。拨过去之后再推油门。

**每一格都要填**，包括你判断"这轮反正不干活"的那些——**「不转」是一条数据，不是省略**。

## 2. 已知的两条现场观察（作者 09-23 口述，待本表复核）

| # | 口述 | 本表要复核成什么 |
|---|---|---|
| ① | 只有**左后轮**在纵向、横向都反 | 第 1 列里左后填「后」，其余三个填「前」——如果成立，要翻的就是 `Roll_LR_Dr` 一个轮，不是整轴 |
| ② | 横向档下**右后轮没有行走电机动作** | 第 3 列右后填「不转」。**这条别当成"随便它"**：横向档是轮序置换（`path_plan.c:548-555`）之后才进输出的，某一轮完全不动，说明置换后那一格拿到的是零指令或方向/使能没给——这恰好是"代码下标↔物理轮"对不对得上的直接证据 |

## 3. 填完怎么交

拍照发我就行，不用誊成文字。我按表做三件事：① 只翻该翻的那一个（或几个）轮；② 重编译并核对 build_log/map；③ 把这张表的结果登记进台账 Hw-23，并写明"上代车实测"，**样机（2.15 m）搬过去后不得继承，按同一张表重测**。

## 4. 一句话范围说明

横向蟹行本身**不是秋季要用的功能**——门 N 是"自主沿行空跑、禁止横移"，AUTO 只走差速。所以第 3 列对"车能不能干活"不重要；它重要是因为它是**映射证据**。别为了修好蟹行去改代码。

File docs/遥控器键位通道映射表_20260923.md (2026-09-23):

# 遥控器键位 ↔ SBUS 通道映射表（2026-09-23 建）

> **用途**：① E3 第 5 件"现场夺权档"要占一个空闲通道，得先知道哪一路真有实体开关；② 缺口清单 C4（SBUS 通道-速度映射表）的前半张；③ 今天排查"车完全不动"时，确认是不是某个开关在掐油门（`ch[6]` 有六处互锁引用）。
>
> **权威分工，不许互相推测**：
> - **通道号 → 固件用途**：由代码定，下表已填，带行号可复核（09-23 逐通道扫全工程，GBK 显式解码并按"该行是否注释"分类）。
> - **通道号 → 发射机物理键位**：**只有发射机能定**，待填。别用"通常 3 通道是油门"这类惯例填它。

## 1. 表（16 行）

| 通道 | 固件用途（代码已证） | 代码位置 | 物理键位（待填） | 拨到底两端的值 + 中位（待填） |
|---|---|---|---|---|
| ch[0] | 工作按钮（作业机构启停） | `path_plan.c:372`「表面工作按钮切换了」、`:379` | | |
| ch[1] | 纵向 ↔ 横向 行走方式 | `path_plan.c:212`、`:221`（写 `Switch_direction_Horizontal_flag`） | | |
| ch[2] | 转弯方式切换（前转/后转…） | `path_plan.c:195`、`:203`（写 `Switch_way_flag`） | | |
| ch[3] | 前进 ↔ 后退 | `path_plan.c:160`、`:167`（写 `control_flag[1]`） | | |
| ch[4] | **油门摇杆**（右手前后） | `path_plan.c:92`、`:178`、`:180`；另 `main.c:318/323/337` 用它判"遥控器居中或断开" | | |
| ch[5] | **方向摇杆**（左右转） | `path_plan.c:288`、`:297`、`:320`（写 `control_flag[3]`） | | |
| ch[6] | 停车 / 推拉杆互锁：低于 1400 即"停止工作" | `uart4.c:458/487/516/544/573/625/676` | | |
| ch[7] | **无活用途**（曾被规划为"缩回"，已注掉） | `path_plan.c:407`（注释行） | | |
| ch[8] | **无活用途**（曾被规划为"低速"，已注掉） | `path_plan.c:350`（注释行） | | |
| ch[9] | 无活用途 | 只有 `telecontrol.c:160` 的解析行 | | |
| ch[10] | 无活用途 | `telecontrol.c:161` | | |
| ch[11] | 无活用途 | `telecontrol.c:162` | | |
| ch[12] | 无活用途 | `telecontrol.c:163` | | |
| ch[13] | 无活用途 | `telecontrol.c:164` | | |
| ch[14] | 无活用途 | `telecontrol.c:165` | | |
| ch[15] | 无活用途 | `telecontrol.c:166` | | |

**订正记录**：v1.0 §4.3 原写"`ch[0]~ch[8]` 已被 path_plan 用满、`ch[9]~ch[15]` 全空闲"，两处都错——7/8 的引用全在注释里（不算占用），0~6 才是真在用。**空闲 = `ch[7]~ch[15]` 共 9 路**。已改（提交 `a1e56b1`）。

## 2. 怎么填（两条路，优先 A）

**A. 用发射机自己的"通道显示 / 伺服显示"页**（约 5 分钟，唯一能一次覆盖 16 路的办法）

1. 遥控器开机进设置，找 Channel Display / Servo Display / 通道监视一类页面。
2. 逐个拨开关、推摇杆，记下**哪一路的数字跟着动**。
3. 每路记三个数：拨到下端的值、中位/松手的值、拨到上端的值。**代码里出现过的判据阈值是 1100 / 1268 / 1300 / 1350 / 1400 / 1450 / 1500 / 1600 / 1700 / 2000**，你记的数要能跨过相关阈值，否则固件根本读不到你的动作。
4. 发射机上根本没有对应开关的通道，直接写"无对应键"，别空着。

**B. 没有通道显示页** → 只能用车上的反应反推，**且只能覆盖 0~6**：

| 想确认 | 动作 | 应看到 |
|---|---|---|
| 油门在哪一路 | 推车上的油门杆 | 车走/屏上速度变 |
| 纵横切换 | 拨一个开关 | **四个轮面转到 90°**（蟹行） |
| 前进/后退 | 拨开关后推油门 | 车换向（注意：往回拉油门不倒车，是设计如此，见台账 Hw-23 ⑧） |
| 停车互锁 | 拨某个开关 | 车立刻不响应油门 |

这条路认不出 7~15（没反应既可能是"空闲"也可能是"你没拨到它"），所以 B 只能当交叉验证，不能替代 A。

## 3. 验收（填完自查这三条）

1. 16 行**每行都有内容**：要么填上键位，要么写明"发射机无对应开关"。
2. **锚点自检**：`ch[4]` 必须落在右手油门摇杆、`ch[5]` 必须落在方向摇杆。对不上说明接收机做过通道重映射（或发射机显示序号≠物理通道号）——**那整张表作废重来**，并把接收机型号与重映射设置记进备注。
3. 从空闲段里指出**至少 2 路"有实体开关且当前无用途"**，供 E3 夺权档使用。预期是 `ch[7]`、`ch[8]`——它们被厂商规划过"缩回/低速"，说明控上大概率真有开关。

## 4. 交回

填完拍照或直接把本文件发我。我据此在 E3 实施里定死夺权通道，并把本表登记进缺口清单 C4（那条现在是 🔴 未开始）。

**今天不要为了建表改车上任何代码**——四轮方向表（台账 Hw-23 ⑦ 要的那张）优先级更高，那张决定车能不能动；这张决定将来怎么安全地抢回来。

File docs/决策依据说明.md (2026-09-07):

# 设计决策依据说明（组会汇报附件）

> 用途：回答"为什么这样设计"。每个决策按固定格式：**结论 / 被否备选 / 理由 / 证据 / 推翻条件**。
> 最后一条"推翻条件"最关键：它说明每个决策都留了退出机制，不是拍脑袋。
> 日期：2026-09-05。对应方案 v0.7、缺口清单、理论材料（式号均可在其中索引）。

---

## 一、任务边界类

### D1 只做行间除草，不做株间
- **备选**：株间单株识别+机械臂拔除（如 Nindamani 方案）。
- **理由**：株间除草的核心难点是"芍药苗 vs 杂草苗"的单株辨别，幼苗期两者形态几乎不可分，是全行业未解难题；而行间除草只需要"行墙边界"，分割目标从"哪棵是草"变成"哪里是行"，问题难度降一个量级。
- **证据**：开题 1.1 与方案 v0.4 §1.1 一致；李俊论文同样只做行间（其"尚未自主行走"恰是我们的空白论据）。
- **推翻条件**：若导师明确要求株间功能，则项目范围变更，需重排全部试验设计。

### D2 机械中耕，不用化学/激光/机械臂
- **理由**：中草药零农残是硬约束，化学直接排除；激光除草单株处理节拍低、成本高，撑不起"3 亩/日"效率目标；机械臂逐株拔除依赖株间识别（见 D1）。
- **证据**：v0.4 §1.1；王硕博士论文同为机械式。
- **推翻条件**：无——零农残是农艺硬约束，不会变。

### D3 种植场景由林下调整为大田（对开题的调整一）
- **背景**：开题（2026-05）面向"林下"场景，强调斑驳光影与树木遮挡。
- **理由**：实际试验田为大田种植，环境约束简化。但开题承诺的"光影鲁棒性"没有丢——秋季采集清单的光照矩阵（晴天顺光/逆光/阴天）就是该承诺的落地形式；分割模型微调仍覆盖多变光照。
- **证据**：开题报告 1.1；采集清单 §2 拍摄矩阵。
- **推翻条件**：若试验田再次变更回林下，需补采林下专属样本并重估投影误差（树冠遮挡影响 IPM 假设）。

---

## 二、机械类
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

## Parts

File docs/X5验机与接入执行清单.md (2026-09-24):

# RDK X5 验机与接入执行清单（2026-09-09）

> 覆盖：到货验机（E2.2 四项）→ B1 烧录 → B2 串口对拍 → B7 车端接入 → B8 链路打流。
> 顺序执行，每项做完在【回填】写结果。所有命令在 Windows PC（Git Bash/PowerShell）或 X5 SSH 终端执行。
> 依据：官方文档 developer.d-robotics.cc（v3.5.0）+ 本仓库缺口清单 B2/B7/B8。

---

## 0. 准备

| 物品 | 状态 |
| --- | --- |
| RDK X5 套餐（含 64G TF 卡 + 读卡器 + 电源） | ✅ 已到 |
| USB-TTL ×2（CP2102，3.3V 挡） | ✅ 已到 |
| CPE 网桥一对 | ✅ 已到（第 5 步才用） |
| 网线 ×1 | 需确认 |
| 回形针/镊子（TF 卡座弹簧） | — |

**关键事实**（官方文档核实）：镜像 ≥3.0.0 = Ubuntu 22.04；SSH `sunrise/sunrise`；串口 `root/root`；eth0 出厂静态 IP **192.168.127.10/24**；40pin Pin8=UART1_TX、Pin10=UART1_RX，**3.3V 电平**（与 STM32 PC6/PC7 直连无需转换，共地即可）。

---

## 1. 烧录系统（E2.2 第 1 项）

1. 下载镜像：https://archive.d-robotics.cc/downloads/os_images/rdk_x5/ → 选**最新 3.x 版本**（Ubuntu 22.04），下载 `.zip` 并解压出 `.img`。
2. 读卡器插 TF 卡 → **Rufus**（https://rufus.ie）→ 选卡 → 选 img → 写入（DD 模式弹窗选确定）。
3. 卡插 X5 卡槽（弹簧卡座，推到底），接电源开机，等 1-2 分钟。

**验收**：板上 LED 正常（红灯常亮/蓝灯闪烁属正常启动序列，以说明书为准）。
【回填】：

## 2. 网线直连 + SSH（E2.2 第 2 项）

1. PC 网口设静态 IP：`控制面板 → 网络 → 以太网 → IPv4`：
   - IP `192.168.127.100`，掩码 `255.255.255.0`，网关留空
2. 网线连 PC ↔ X5 网口，`ping 192.168.127.10` 通。
3. SSH：`ssh sunrise@192.168.127.10`（密码 `sunrise`）；首次确认输 `yes`。
4. 查版本：`cat /etc/version`、`rdkos_info`。

**验收**：SSH 进去，版本 ≥3.0.0。
【回填】：

## 3. UART 自发自收（E2.2 第 4 项提前做，X5 单板即可验）

1. SSH 后装 pyserial：`sudo apt update && sudo apt install -y python3-serial`
2. 列串口：`ls /dev/ttyS*`；`dmesg | grep -i ttyS` 看哪个对应 40pin UART1（预期 `/dev/ttyS1`，Pin8/10）。
3. 若串口被 console 占用或无设备：`sudo srpi-config` → Interface/40pin 复用里启用 UART（以菜单实际项为准）。
4. **短接 Pin8 与 Pin10**（杜邦线），跑：

```bash
python3 - <<'EOF'
import serial
ser = serial.Serial('/dev/ttyS1', 115200, timeout=1)
ser.write(b'PING123')
print('rx:', ser.read(7))
EOF
```

**验收**：打印 `rx: b'PING123'`。
【回填】：

## 4. B1+B2：固件烧录 + PC↔STM32 对拍（USB-TTL #1，大板桌面完成）

1. **B1 烧录**：Keil `Flash → Download`（或 STM32CubeProgrammer）烧
   `firmware/大车proj/大车/OBJ/PWM.hex`。
   - ⚠️ **`OBJ/` 被 .gitignore 忽略（`.gitignore:11`），hex 只存在于构建它的那台机器上**，
     不在 git 里。丢了/怀疑不是同一份，就重建：
     `D:\ruanjian\keil\KEIL32\UV4\UV4.exe -r firmware\大车proj\大车\USER\PWM.uvprojx -j0 -o build_log.txt`。
   - **认版三处（09-22 刚实测，旧注"Code=44616"是 09-08 那版，别按它判）**：
     `USER/build_log.txt` 末行 `0 Error(s), 60 Warning(s)`；同文件
     `Program Size: Code=44848`；`OBJ/PWM.map` 内
     `retrofit_sbus_ok 0x0800886b Thumb Code 28 retrofit.o(.text)`。
     第三条同时是 E2③（SBUS 帧长判据）真的进了镜像的证据。
   - 验收：上电行为与烧录前一致（遥控可开、刀不动，MANUAL 默认态）。
2. **接线**：USB-TTL 插 PC → 大板 USART6：PC6(TX)→TTL RX、PC7(RX)→TTL TX、**共地**；跳线帽确认 3.3V 挡。
3. **对拍**：设备管理器查 COM 号（如 COM5）→

```bash
python common/uart_vectors.py COM5
```

**验收**（缺口清单 B2）：① 6 组有效帧不崩、0x10 状态帧 20Hz 出现；② `bad_crc_must_reject`/`truncated_must_reject` 静默丢弃；③ PC 收到的状态帧 CRC 全过。
【回填】：

## 5. B7：X5 接入链路（E2.2 第 3 项推流 + UART 换线）

1. **推流验证**（先网线直连）：X5 上 `ls /dev/video*` 确认相机（USB3.0 UVC 相机接 X5 USB3.0 口）→ 跑本仓库 `vehicle/stream_pi.py`：

⚠️ **09-22 订正：下面这段原来写的是 `stream_pi.py 192.168.127.100`，那是 H.264/UDP-TS 时代的旧命令，现在照抄会直接崩**（`stream_pi.py` 的第一个参数是**端口号**，不是 IP：`int('192.168.127.100')` 抛 ValueError）。链路早已定型 TCP multipart MJPEG，X5 是**服务器**、PC 主动连出去，所以不需要 PC 侧放行入站。

```bash
# X5 上（仓库先拷过去：PC 侧执行
#   ssh sunrise@192.168.127.10 "mkdir -p ~/qoder"
#   scp -r "D:/ai work/qoder/vehicle" "D:/ai work/qoder/common" sunrise@192.168.127.10:~/qoder/
# —— vehicle/ 与 common/ 必须在同一个父目录下，bridge.py 是往上一级找 common 的）
ls /dev/video*
python3 ~/qoder/vehicle/stream_pi.py          # 默认听 0.0.0.0:5000；要换端口才传数字
# PC 上（Git Bash）——两个参数可选：host port，默认就是 192.168.127.10:5000
python -B tools/stream_view.py                # 键：q 退出，s 存一张带时间戳的截图（秒表测时延用）
```

X5 上 gstreamer 若缺：`sudo apt install -y gstreamer1.0-tools gstreamer1.0-plugins-{base,good,bad,ugly}`。

2. **UART 换线**：拔 USB-TTL，改接 X5 40pin：Pin8(TX)→大板 PC7(RX)、Pin10(RX)→大板 PC6(TX)、Pin6 GND→共地（**3.3V 直连，无需转换**）。
   - ⚠️ **换线前先看这条（09-23 依 `大板.pdf` 厂商装配注重写；撤回我此前转述错的位号）**：
     U7 块有**两条并联支路**——「485: **R15、R16 默认焊接**」与「**R25、R26 默认不焊接** = TTL 直通 T6」。
     作者 09-23 已焊 R25/R26（**选对了路**），但 **R15/R16 还在 ⇒ U7 的 RO 仍挂在 PC7 网络上**，
     并联一条新路不等于旁路旧器件。MAX13487 引脚（PDF 直读）：1 RO / 2 RE# / 3 SHDN# / 4 DI / 5 GND / 6 A / 7 B / 8 VCC。
     **本路线唯一需要的动件 = 拆掉 R15、R16**，拆后 T6 就是纯 TTL，不必再去证明"眼下没撞上"。
     旧文"U7 那路选型 0R 是 R23/R13、两颗都贴着"**位号错了**（R13/R14/R23/R24 属 U8 块）；
     "该系列无 DE/RE"也不准（无 DE，但确有 RE# 与 SHDN#）——见台账 Hw-1。
   - **链路判据（拆不拆都要过：双向 + 错误率）**：`bench_status` 的 `rx_bad` 长期为 0（偶发 1 个 CRC 错也算没过）；
     且跑 `pc/main.py --live` 让 PC 真发指令，看大板 STATUS 的 `mode` 字段是否跟着变。**单向收到 STATUS 不算通。**
   - T7 通断仍未量（保留待办：若回到 T7 就能省掉这两颗电阻的拆装）。作者当前选择 = T6 + 焊 R25/R26。
   - **严禁**把这条链路挂到 485 第 1/2 路（A_1/B_1、A_2/B_2，原车轮角编码器在用）。
   - X5 供电走自带电源 / 独立 48→5V Buck，**不要从大板 5_A_V/5_B_V（各 1.5A）取电**（推流+推理峰值会拉垮 5V 轨导致复位）。
3. **改配置**：`vehicle/config.yaml`：`serial_dev: /dev/ttyS1`（以第 3 步实测节点为准）、`pc_ip: 192.168.127.100`。
   - ⚠️ **09-22 订正（原来这句写错，会误导人换桥时去改 IP）**：本行旧文写"网桥阶段改为 PC 网桥侧 IP"——
     CPE 是**透明网桥、同网段**（见下面 §6 第 2 步：换桥后"PC 恢复 192.168.127.100"），
     **换桥不需要改 `pc_ip`**，它两端都是 127.100。网桥自己的管理地址（192.168.2.1/2）是配桥用的，
     不要填到这里。真正要改的只有一种情况：你给笔记本另设了别的网段。
4. **跑 bridge**：X5 上 `python3 vehicle/bridge.py`；PC 上 `python pc/main.py --live --pi-ip 192.168.127.10 --no-gui`（先别进 AUTO，看 STATUS 收包：HUD/CSV 出现 mcu_mode/batt_v 即 D7 链路通）。
   - ⚠️ **`pc/main.py --live` 与 `tools/bench_status.py` 都绑 UDP 9100，互斥**（`pc/status_rx.py:19`）。
     要看画面/跑闭环 → 开 main.py；**要做 B2 取证 → 关 main.py，只开记录器**（它把每帧、每次模式跳变、
     每段静默 gap 和你敲的场景标记写进同一张带绝对时间戳的 CSV）。记录器拒启时会点名是谁占着端口。
   - `batt_v`/`current_a` 两列在固件里是占位（`retrofit.c:226` 写死 48.0f），**有值≠测到了**，别看它以为电池链路通了。

**验收**：PC 出实时 720p 图（秒表对比法时延 <100ms）；STATUS 帧经 X5 转发到 PC，rx_good 持续增长、rx_bad=0。
【回填】：

## 6.5 网桥台架验证 ✅（2026-09-11，正式 B8 拉距前的台架结论）

- 配对：O1-5G 网桥一对（AP 192.168.2.1 / 客户端 192.168.2.2，SSID Tenda_YDH，CH157 5GHz，透明网桥已启用，信号 -24/-36dBm，SNR 28-32dB）
- 链路：PC(127.100) ↔ 桥A ~~无线~~ 桥B ↔ X5(127.10)，ping 0% 丢包，RTT 1-4ms
- 推流：TCP MJPEG 1080p30 走桥，28.7-30.5fps，首帧 40ms，端到端 **104-225ms**（5 次秒表同框采样，均值 ~155ms；网线直连基准 90-105ms，桥加约 50ms 均值+抖动）
- 结论：台架通过；视频大帧对无线抖动敏感属预期，**B8 正式验收以控制帧 p95 <50ms 为准**（视频均值 200ms 内即接受）
- 运维教训：X5 eth0 运行态偶发挂死（换链路对端后必现一次），**失联第一步 = 断电重启 X5**（30s 恢复，配置无损）

## 6. B8：网桥替换网线 + 打流（一票否决）

1. PC 网口改接网桥 LAN；两台网桥按说明书配对（默认出厂多即插即用，同网段透明桥——不通再进网桥管理页配 SSID/信道）。
2. X5 IP 仍为 192.168.127.10，PC 恢复 192.168.127.100，`ping` 通即可。
3. **打流**（田间距离 120m 模拟：先把两台网桥拉开实际作业距离再测）：

```bash
ping -n 100 192.168.127.10        # Windows
# 控制帧打流：pc/main.py --live 跑 10 分钟，看 rx_good/rx_bad 与 latency 列
```

**验收**：丢包 <1%，控制帧 p95 <50ms；**不达标 → 调网桥朝向/信道，直至达标才准进 M2**。
> ⚠️ **测量口径（2026-09-14 复审更正）**：`pc/main.py` run_log 的 `latency` 列计时始于取帧后，测的是**感知处理耗时**，不是控制往返；`rx_good/rx_bad` 也不是丢包分母。控制帧 p95 须用**专用往返打流工具**（发 NAV→收 STATUS 配对计时）单独测；视频同框时延、网络 RTT、控制帧往返、感知耗时**四项分开报**。
【回填】：

---

## 已知坑位（来自台账，测试时对照）

- **printf 污染**已修（fputc 置空），若状态帧出现乱码字节先查这个回归。
- **坏帧报警**：PC 端若 HUD 出现 `bad:` 计数增长或 1 秒 ≥5 报警 → 固件/Python STATUS 字段失同步，停下对 0x10 帧长度（14 字节）。
- **bridge 看门狗**：PC 60 秒无帧才注入 ESTOP，纯遥控测试时不会被锁死（F+ P1）。
- **E2.5 待确认**：拍刀继电器端子照片（P0-7 刀控重做的输入），本次上车顺手做。

## 验机四项结论（E2.2 约定：全过再放，不过 7 天内退换——该店不支持无理由）

| # | 项 | 结果 |
| --- | --- | --- |
| 1 | 烧系统 | ✅ RDK OS 3.5.0 / Ubuntu 22.04.5，x5_rdk_v2 |
| 2 | SSH | ✅ 网线直连 192.168.127.10，sunrise/sunrise |
| 3 | 推流 | ✅ TCP multipart MJPEG，30.5fps，**端到端 105ms**（秒表同框法，2026-09-10） |
| 4 | UART | ✅ **/dev/ttyS1**（40pin Pin8/10），115200 回环 PING123 |

> 验机过程中的实测教训：① 相机 USB 线材/接口接触不良反复掉设备（dmesg: error -71），**上车必须换优质 USB3.0 短线并直插蓝口**（并入 F6 防护清单）；② OpenCV 5.0 的 FFMPEG 后端打不开中途加入的 UDP TS 流（isOpened False 30s 超时），且 MJPEG 整帧 118KB 超 UDP 65507 上限——**视频链路定型为 TCP multipart MJPEG**（`tools/stream_view.py` 接收，105ms 实证）；VLC 缓冲 ~1s 不可用于时延验收。

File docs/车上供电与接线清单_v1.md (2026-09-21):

# 车上供电与接线清单（qoder 版 v1）

> ⚠️ **本文件已被取代（2026-09-21 核对）**：权威版是同目录 `车上供电与接线清单.md`（方案 B 定稿 v4 · 采购详版，198 行，09-12 17:52，比本文件 16:49 更晚且更全）。本文件仅存档，不要再据此采购或接线；两处若冲突以 v4 为准，v4 缺的再回看这里。

> 日期：2026-09-12
> 作者工作区：`D:\ai work\qoder`（本文件为 qoder 侧权威版本；zcode 侧同名文档为其对应物，二者以本项目记忆 `project-hardware-power` 为事实源）
> 面向：非电气背景，尽量大白话。用途：采购 + 接线直接照做。
> 前置问题：RDK X5 与网桥原本都配 **AC→DC 电源砖**，但**车上没有交流电/插排**。
> 结论：**不用 AC、不用逆变器；直接用车上 48V 直流降压给两个设备各自单开供电。**

---

## 0. 已确认的设备事实（采购前先认这三条）

| 设备 | 供电要求 | 来源 |
| --- | --- | --- |
| **RDK X5（车端大脑）** | **USB-C 供电口，需要 5V/5A（25W）** 的电源——**官方手册明确**："接口 1 作为供电接口，需要使用支持 5V/5A 的电源适配器" | 用户阅官方手册确认（2026-09-12） |
| **Tenda CPE 网桥（一对）** | **9–13V DC 直供**（≈12V/1A）**或 PoE 网线供电**；配一个 injector（DC 口 + PoE 口 + LAN 口） | 设备铭牌/手册 |
| **笔记本网口** | **只传数据，不供电**（RJ45 网口无 PoE）→ PC 端网桥必须自带电 | 通用常识 |

> **重要更正**：本清单早期版本曾写"RDK 接受 12V"——**那是错的，作废**。RDK X5 是 **5V/5A**，**不要给 12V**（会把 5V 供电口打坏）。给 **5V** 才安全。

---

## 1. 供电方案（一句话）

**车上 48V 电池 → 各加「保险丝 + 防浪涌(TVS) + 磁环」→ 两条独立降压：**
- 一路 **48V → USB-C 5V/5A** → RDK X5；
- 一路 **48V → 12V/≥1.5A** → 车端网桥 DC 圆口。

两条**都单开**（**不挂大板那条 12V/5V 共享轨**）。

**为什么单开、不蹭大板**（大白话）：
- 大板那条 12V 已经养着 HMI 屏、继电器、MP3——它们一开一关会让电压"抖"；
- 它和"动力大板"共用一条命，电机一冲会连累大脑；
- 我们要"急停后还能看到画面"，所以大脑/链路要接在**急停切不断**的那一路电上。

**为什么 PC 端网桥不能用笔记本网口供电**：笔记本网口只走数据、不送电。PC 端那台网桥得自己带电（见 §3）。

---

## 2. 车上要买（采购单）

| # | 物品 | 关键参数（照抄给卖家） | 用途 |
| --- | --- | --- | --- |
| 1 | **48V → USB-C 5V/5A 宽压模块** ×1 | 输入 **46–54V**；输出 **USB-C、5V、≥5A**（≥25W）。**认准 5A，不是 5V/3A** | 供 **RDK X5** |
| 2 | **USB-C 线（过 5A）** ×1 | 带 **e-marker**、支持 5A 的短线（普通细线带不动 5A，会压降/掉电） | 连 RDK |
| 3 | **48V → 12V 降压模块** ×1 | 输出 **12V、≥1.5A**（网桥 ≈12W） | 供 **车端网桥** DC 口 |
| 4 | **保险丝座 + 保险丝** ×2 | 装在各路 48V 进线处；RDK 路选 **2A**、网桥路选 **1A**（48V 侧总电流 <1A，裕量足） | 过流保护 |
| 5 | **防浪涌 / TVS 模块** ×2 | 跟卖家说"**48V 车用、防电机尖峰**" | 抑制电机噪声尖峰 |
| 6 | **抗干扰磁环** 几个 | 套在 USB-C 线、网线、电源线上各一个 | 抗干扰（EMI） |
| 7 | **12V 圆口公头线** ×1 | 插头**尺寸/正负极先对上网桥 DC 口**，别硬插 | 连网桥 |
| 8 | 短线材 / 端子 / 热缩管 / 共地线 | 若干 | 接线 |
| 9 | *(推荐)* **USB-C PD 电压/电流表** ×1 | 能显示电压/电流的小表（¥30–50） | 上电后实测 X5 实际电流，确认 ≥5A 不欠压 |

> **必须避开的坑**：市面上大量"5V USB-C 车充/降压"只有 **5V/3A（15W）**——**喂不满 RDK 的 25W，满载会掉电重启**。下单只认 **5V/5A**。
> 可选加分：模块若**支持 USB-C PD 协商并广播 5V/5A** 最稳；纯 5V/5A 固定输出也可（X5 手册写的是"支持 5V/5A 的适配器"，不强制 PD）。二者区别只在 USB-C 侧要不要"对话"，都能用。

---

## 3. PC 端要备

- 一个 **能输出 12V 的便携电源**（12V 输出的 PD 充电宝，或一小块 12V 锂电池）——田头给 **PC 端网桥**供电；电压对上 9–13V。
- 室内/有插座处：直接用网桥**原厂 AC 适配器**。
- 笔记本网口那根网线**只管传数据**。
- 注：PoE 不省电源——injector 自己也要先有电，等于没简化。

---

## 4. 车上怎么接（网桥不架高）

```
48V 电池(46–54V)
   │
   └─[保险丝+TVS+磁环]─┬─ 48V→USB-C 5V/5A 模块 ──USB-C(5A 线)──→ RDK X5
   （取"急停不断"那一路）│
                        └─ 48V→12V/1.5A 模块 ────12V 圆口线───→ 车端网桥 DC 口

RDK 网口 ──普通短网线──→ 车端网桥 LAN 口
（RDK ↔ PC 走网桥的无线点对点）

全车共地：RDK / 网桥 / 两颗降压模块 / 大板 / 电池负极 —— 接同一个参考点
```

要点：
- **都要 5V，不要 12V**：RDK 只认 5V/5A，接错电压先烧板。
- **只给 RDK 5V/5A**：网桥是 12V，别混。
- **共地**：所有地接同一电位（逐点量通断 <0.1Ω），否则信号对不上、易烧串口。
- **急停那一路取电**：让 RDK+网桥在急停后仍带电，便于看画面/读状态；**MCU 侧安全不依赖 RDK 在线**（由固件 ESTOP 锁存 + 看门狗保证）。

---

## 5. 现场安全与安装建议

- **加一个总开关**：停车时断开电子设备，避免 48V 电池被持续空耗（X5 待机也有功耗）。
- **48V 是电机母线、噪声大**：磁环 + TVS 是下限；电源线尽量**远离电机动力线**。
- **散热**：X5 满载（BPU 推理）可达 ~25W，5V/5A 模块要留散热空间。
- **线材/接口**：相机 USB 曾两次掉设备（接触不良）——上车**换优质短线、直插 USB3.0 蓝口**，是同一类"接口别省"的问题。

---

## 6. 待现场核实（上车前逐项打勾）

- [ ] 用 PD/电压电流表实测：X5 上电后 USB-C 是否为 **5V、电流是否够（负载下不掉到 5V 以下）**
- [ ] 网桥原厂适配器标签电压/极性 = ?（确认是 12V 档、极性对）
- [ ] 急停取电点是"**常电**"（万用表实测：按急停后该点仍带电）
- [ ] 48V 侧保险丝规格与两路总电流匹配（实测）
- [ ] 降压模块满载温升可接受
- [ ] 共地逐点通断 <0.1Ω

---

## 7. 与 zcode 版清单的差异说明

- 本版**已把 RDK 供电定为 5V/5A**（手册确认）；zcode 版 §0 的 5V/5A 结论一致，但其 §1 曾"推荐绕开 PD 用 5V 直降"——**5A 属 USB-C 高电流档**，若走 PD 协商更稳，纯 5V/5A 固定输出亦可用（见 §2 注）。
- 本版删除任何"RDK 接受 12V"的历史措辞。
- 本版新增：**5A 必须配 e-marker 线**、**5V/3A 陷阱**、**PD 表实测**三条操作项。

---

*变更记录：v1（2026-09-12）—— 首版；确立 5V/5A、双路单开、网桥不架高、PC 端网桥自带电、保险/TVS/共地/急停常电。*

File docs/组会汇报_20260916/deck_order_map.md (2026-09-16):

# 组会汇报 deck 页面清单与溯源表（2026-09-16，第 4 版）

- 交付物：`组会汇报_纯视觉芍药行间除草机器人_20260916.pptx`（17 页，16:9，全可编辑）
- 生产路线：**Route C 务实回退**；本表由 `gen_map.py` 从 plan + 证据合同自动生成，不与 deck 脱钩
- 校验：`validate_paper_analysis.py` passed；`validate_pragmatic_fallback_pptx.py` passed（0 issues）；PowerPoint COM 导出 17 张 PNG 逐页目视
- 第 4 版变更：按汇报人要求**删除全部 13 处页底红字 takeaway**，并删除结尾页的三条讨论问题（`AGENT_CLOSING_META`）—— 汇报人删过的内容一律不加回；原红字承担的两处限定词（纯函数复现、电流阈值须标定）折进 bullet 本体，口径边界只保留在本表与证据链 caution 字段

## 展示图清单

**全 deck 无任何展示图**（17 页 `figure_count` 合计 0）。分割实际输出、导航线叠加、整机照片由汇报人现场展示。下表『溯源记录』不是展示图，是每个数字的出处登记。

| 页 | 导航段 | 版式 | 标题（结论式） | 证据链 | 关键数字的溯源记录 | 口径边界（口头也不可怕，但不可越） |
| --- | --- | --- | --- | --- | --- | --- |
| 1 | 立题与约束 | cover | 纯视觉芍药行间除草机器人 | — | — | — |
| 2 | 立题与约束 | text | 行间除草是芍药管理的劳力与成本瓶颈 | e_labor | f_labor: ch01_draft.md 第8行 人工除草成本；f_agron: ch02_draft.md 第14、18行；ch05:8 | 成本数字的文献出处尚未核验，汇报时按背景陈述不作定量论据 |
| 3 | 立题与约束 | summary | 农艺约束框定了样机的设计边界 | e_agron | f_agron: ch02_draft.md 第14、18行；ch05:8；f_frames: avi_frames/ 295 张 1920x1080 田间抽帧 + data/calib_params.npz | 三项均为设计目标值，未登记的项必须标待实测，不能补常识值 |
| 4 | 除草机构选型 | text | 八类除草机构逐个筛，六类被排除 | e_screen | f_table23: ch02_draft.md 第86-101行 表2-3 八类除草机构机理与适用性；f_decisions: 决策依据说明.md D2/D4/D6（第17-18、32-33、43-46行）；D8（第58行）已过时 | 商品机型与中文核心期刊机具文献缺失，筛选覆盖面有限，需说明为针对性检索 |
| 5 | 除草机构选型 | comparison | 入选两类：鸭掌铲主选，弹齿作对比 | e_pick | f_table23: ch02_draft.md 第86-101行 表2-3 八类除草机构机理与适用性；f_actuator: 参数差异台账.md Hw-9 第46行 电推杆规格 | 鸭掌铲幅宽尚未登记，与弹齿 250mm 对比条件不对等，须先补齐 |
| 6 | 设计与控制原理 | process | 技术路线：单一相机到刀具位移的四段链路 | e_route | f_ipm: tools/morph_process.py 第189-193行；camera_calib.py 第55-73行；f_drive: network/nav_control.py 第134-155行 Ackermann4WS；pc/control.py DifferentialDrive | IPM 参数仍为硬编码，链路在真实秋季域上尚未闭环验证 |
| 7 | 设计与控制原理 | text | 跨 4 行作业，3 条草带由 2 侧刀加 1 中间刀清除 | e_arch | f_actuator: 参数差异台账.md Hw-9 第46行 电推杆规格；f_slide: 参数差异台账.md Hw-7/Hw-12 第44、50行；ch02:117 滑台参数；f_board: docs/大板实物标注.jpg（1080x1920，13 处编号标注） | 整机装配照片缺失，本节结构关系以现场展示为准 |
| 8 | 设计与控制原理 | comparison | 底盘粗纠偏加刀具细对行，比只纠底盘更可行 | e_twolevel | f_slide: 参数差异台账.md Hw-7/Hw-12 第44、50行；ch02:117 滑台参数；f_pid: pc/control.py 第27行起 PID；pc/main.py 第209行调用 | 滑台未接线，刀具一级的实际带宽与精度尚无实测 |
| 9 | 设计与控制原理 | text | 分割选 DeepLabV3+ | e_seg | f_miou: network/train_metric_log.csv 第76行（epoch 76），共 202 行 | 该值是夏季域验证集结果，秋季域指标尚未产出；最终 checkpoint 与划分需冻结 |
| 10 | 设计与控制原理 | text | 分割分数不等于能导航，评价要分三层 | e_seg_limit | f_miou: network/train_metric_log.csv 第76行（epoch 76），共 202 行；f_ipm: tools/morph_process.py 第189-193行；camera_calib.py 第55-73行 | 导航线横向误差与失效分层的真值还未标，三层里只有第一层有数 |
| 11 | 设计与控制原理 | process | 行墙提取分远近两场，三条目标线要分开 | e_navline | f_ipm: tools/morph_process.py 第189-193行；camera_calib.py 第55-73行；f_frames: avi_frames/ 295 张 1920x1080 田间抽帧 + data/calib_params.npz | 单墙回退仍是粗偏移，低机位标定未做，秋季帧上的有效性未测 |
| 12 | 设计与控制原理 | text | 轨迹跟踪用 PD 加横向速率阻尼 | e_track | f_drive: network/nav_control.py 第134-155行 Ackermann4WS；pc/control.py DifferentialDrive | 未台架验证；阿克曼几何是实现细节不作创新点，不得称已实现四轮转向自主控制 |
| 13 | 设计与控制原理 | text | 中间刀还不能叫闭环：刀到位了，相机看不出来 | e_toolctrl | f_pid: pc/control.py 第27行起 PID；pc/main.py 第209行调用；f_proto_tool: common/protocol.py 第109-111行 pack_tool(offset_mm, lift) | 复现是纯函数结果，不证明整车行为；刀位反馈通路目前不存在 |
| 14 | 设计与控制原理 | summary | 升降管三梁、横移管中间刀，两套机构 | e_lift | f_actuator: 参数差异台账.md Hw-9 第46行 电推杆规格；f_slide: 参数差异台账.md Hw-7/Hw-12 第44、50行；ch02:117 滑台参数；f_board: docs/大板实物标注.jpg（1080x1920，13 处编号标注） | 电推杆接入方式仍待继电器板实物确认，滑台未接线 |
| 15 | 进土深度问题 | text | 开放问题：刀上发生了什么，机器不知道 | e_depth | f_lift_bits: retrofit.c 第12行与第244-258行 apply_outputs；f_proto_tool: common/protocol.py 第109-111行 pack_tool(offset_mm, lift)；f_limits: retrofit.c 第14行注释与第275-281行 stepper_update | 不得写成定深精度问题，也不得声称电流硬件已覆盖推杆回路 |
| 16 | 进土深度问题 | summary | 分两层解：先机械保机，再电流辨草 | e_depthfix | f_decisions: 决策依据说明.md D2/D4/D6（第17-18、32-33、43-46行）；D8（第58行）已过时；f_actuator: 参数差异台账.md Hw-9 第46行 电推杆规格 | 机械卸载结构未设计；电流判据在未标定前不得称可用 |
| 17 | 小结与讨论 | closing | 请各位老师同学批评指正 | — | — | — |

## 讲这页时要挡住的反问

- **第 3 页**：行距 30~40 cm、坡地 0~15° 为汇报人 09-16 现场确认值，与论文 `ch02:14` 的 30~60 cm、5~15° 冲突；按事实权威序以现场值为准，论文待改（台账 Hw-19）。

- **第 4-5 页**：为什么没有第三种刀 → 表 2-3 六种排除理由各自成立，ch05 组1 既定对比就是鸭掌铲 vs 弹齿；加第三种会同时改刀头与控制两个变量，归因不清。

- **第 8 页**：两级纠偏做了吗 → 没有，滑台未接线，本页是分工设计（proposed），实测排春季。

- **第 12 页**：你不是四轮转向吗 → 硬件具备该能力，当前 AUTO 只用轮速差；能力／拟用模式／已运行模式三者分开说。

- **第 13 页**：刀移过去图像偏差为什么不变 → 相机在车架上，量的是行相对车；这就是还不能叫闭环的原因。50 mm 限幅那组数字是**纯函数复现**，被问到必须说明不是整车实测。

- **第 15-16 页**：论文里不是写了深度监测？→ `ch04:50` 的摆角传感器无任何硬件登记，属过度声明，本次不采用。电流判据在标定前不得称可用；板上 ACS712 登记对象是**行走电机回路**，是否覆盖推杆未跟线。

- **口头要提的三件事**（页面上不写）：进土深度走哪条路 / 鸭掌铲幅宽何时补测 / 春季田块需书面确认。

## 交付声明

```text
Image2 backend used: no
Delivery mode: pragmatic editable fallback accepted by user
Visual style: sample-deck-derived white/red/black academic grammar
Scientific visuals: none displayed（数据图与整机照片由汇报人现场展示）
Structural QA completed: yes（17 页，0 issues）
Render/layout QA completed: yes（PowerPoint COM 导出 17 张 PNG + 目视复核）
Editable elements may exist: yes
```

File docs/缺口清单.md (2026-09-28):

# 缺口清单（详细执行版）— 2026-09-02，对照 v0.7 方案

> 用途：这是项目的唯一"欠账台账"。每项给出：**做什么 / 为什么还卡着 / 具体怎么做 / 验收标准 / 预计耗时 / 依赖**。
> 完成一项就在编号前打 ✅ 并写日期。每周五对照本表过一遍（对应排期周里程碑）。
> 状态标记：🟢 已完成 ｜ 🔴 未开始 ｜ 🟡 进行中 ｜ ⚪ 可选/暂缓

---

## 📊 总览：做完的 / 没做的（2026-09-22 快照，qoder HEAD `1c9bdea`）

> **口径**（AGENTS 审查清单第 5 条）：已设计 ≠ **已编码** ≠ **已编译** ≠ **已台架** ≠ **已田间**，逐态分列。
> 测试通过条数、"Keil 0 错误"、150 这个数字本身，**都只证明编码/编译层无回归**，不构成台架或田间证据。
>
> **总判定：所有安全与控制权限类改动，最高只到「已编码 + 已编译」，0 项达到「已台架」。**
> ⇒ 两条硬禁令继续生效：① 禁止实车 AUTO；② 禁止按现有接线文档直接带动力接线。
>
> ⚠️ **解除条件分两条道，别记成一道**（v1.0 §4.1 的拆分，本板过去只写 B5，会读成"秋季也得先过 B5"——
> 那正是 09-21 R2 要杀的口径）：
> · **门 N（秋季导航验证：自主沿行空跑、刀具锁定提刀、禁横移）** ＝ B1 烧录 → B2 对拍（含 SBUS 失联两子情形）
> → 导航专用安全三项（模式切换可观测、链路失联停车、刀具物理锁定确认）。**不含 B5。**
> · **门 F（落刀作业、除草率/伤苗率、主动对刀对照）** 才要 **B5 安全动作实测全项** + 刀控 P0-7 + 滑台接线 + V3。

### ① 🟢 已做完（代码 / 编译 / 单测留证，只等硬件复验）

| 项 | 做到哪一态 | 证据（可复核） | 还差什么才算"完" |
| --- | --- | --- | --- |
| A1–A12 代码侧交付 | 已编码 | 09-14 收工时 89 passed（当前基线见上，不沿用旧数）；Keil 0 错误 | ② 台架 / 田间复验 |
| H1.1 / H1.2 数据资产护城 | 已编码 | `tests/test_data_tools.py` | — |
| **H1.3 / H1.6 分组划分 + 清单冻结**（含 09-21 E1② 与 09-22 命名陷阱） | 已编码，未冻结 | `split_dataset.py` 分组模式 + `split_manifest.json`（`9e5774c`）。**09-21 E1②**：三集合各≥1 组（旧写法恰 3 组时 test 为 0），<3 组**报错拒绝**不静默退回逐图。**09-22 补**：分组形态诊断与"文件名没带批次号→整批塌成一组"的命名陷阱提示；`scan_pairs`/`pre_annotate` 拒绝嵌套目录；非 `.jpg` 点名不再静默漏出 | 等 C1 秋采数据才能冻结；**机制建好 ≠ 泄漏已证伪** |
| H1.4 权重输出路径 / H1.5 混写拒绝 | 已编码 | `SAVE_WEIGHT_DIR` 指回工作区；混写场景 2 例 | 真跑一次训练确认落盘位置 |
| **H2.1 / H2.5 / H2.6 权限与桥接（含 F3）** | 已编码 | `state_machine.py` 契约 + 4 测试；`bridge.py` `last_real`/`last_inject` 拆分 + 4 例。<br>**F3**：`retrofit_on_tool_frame()`（`retrofit.c:105`）只查长度与急停、**不查模式**，横移执行（`:251`）同 ⇒ 只给 NAV 加权限门**挡不住非当前指令源的 TOOL**。权限契约须覆盖"全部执行命令"。**静态路径分析，未做硬件动作测试**（详见 v1.0 §4.3 与 §13） | ② 的 ①②⑥⑧ |
| **H2.2 / H2.3 / H2.4 固件侧**（含 E2③ SBUS 帧长、SBUS 心跳按有效性门控） | 已编码 + 已编译 | 09-21 `UV4 -r`：**0 Error / 60 Warning / Code=44848**，hex+map 已再生，`PWM.map` 内 `retrofit_sbus_ok@0x0800886b`。（09-14 为 61 警 / 44840 / @0x08008863；少的正是 `UART1_Rec_Len` "算了但没用"，地址整体 +8 字节与 Code 增幅自洽。）`telecontrol.c:142` 现三条件与判（长度 35 + 帧头 0x0F + XOR）；`:161-171` 心跳只在帧有效时刷新（旧写法浮空线乱码喂狗） | 烧录 + ② 的 ③④⑤⑦（此处 ⑦＝下表"已知遗留"，非 F3） |
| H2.7 前轮 Ackermann 几何 | 已编码 | `tests/test_nav_geometry.py` 5 例 | 台架转角对拍 |
| H2.8 STATUS 新鲜度 / 序号（**前半**，含 09-21 E1①） | 已编码 | `status_rx.py` `STALE_S=1s`、u16 序号、`out_of_order` +3 测试；**E1①** MCU 重启后重新同步（连续 ≥50 帧序号互不相同且递增且已判 stale；**只恢复状态显示，不恢复 AUTO、不清急停锁存**）+4 测试 | 后半未做 → ③-B（属 E3） |
| H2.9 时延验收口径 | 已改文档 | X5 清单 + v1.0 四项分列 | 实测四项数值 |
| **H3.1 / H3.2 live 链路 + E2④ 有界读** | 已编码 + 已单测，**未与真机联调** | `common/mjpeg.py` **15 测试**：删阻塞生成器 `iter_frames`（调用即报错），换 `StreamFeed`——读线程扛超时与重连，控制循环只调非阻塞 `get(max_age_s)`；`pc/main.py` 无帧拍给 `NO_FRAME_RESULT` 不拿旧图再推理；`VISION_LOSS_S` 与 GUI 按键在流断时可达；`run_log.csv` 加三列 | 真机 X5 联调 + B7 |
| H4.1 / H4.2 / H4.3 / H4.5 论文口径 | 已改入文稿 | chucao_prj `be9093a` 三条手术提交 | 送审前整章通读 |
| H5.5 `train_m.py` NameError | 已编码 | test 分支改 `t_*` 计数 | — |
| **整车空间判据 + 预标注入口** | 已编码 | `geometry_check.py` **7 测试**——**09-22 更正：旧版"+8 测试（60 cm 车只放得下 2 把刀、且需压行行走）"里的压行推论已撤回**，该工具现在只报事实（几个行距／残差／是否可能对得上行），压苗与否须 M14/M15 实测；`pre_annotate.py` **6 测试**（默认不覆盖人工标注、同名冲突拒绝），`deeplab` env 与 anac 基解释器均实测可跑 | 作者量完 M14/M15 才能定 ch02 与 deck 怎么改 |
| R3 整机空间口径 | 🟡 车宽已定，横断面未定 | "量车"这一半已关：`ch02:14` 的 ≤60 cm 是硬错误（样机 2.15 m / 上代 3.25 m）。剩下的阻塞换了问题：轮迹对行线偏差、胎宽、保护带、跟踪误差四项未测（M14/M15 + N1），**伤苗率分母口径因此未定** | **门 N 第一步**：拍横断面 + 量 M14/M15 → 定"一次几条带" → 再改 ch02 / deck / V4 布样 |
| **台架记录器 `tools/bench_status.py`** | 已编码 + 已单测（6 例） | v1.0 §4.1 "门 N：用户执行，qoder 出验收脚本"那句的实体；STATUS→CSV 带模式跳变/静默 gap/人工场景标记同一时间轴 | **本批就是拿它跑 B1/B2**；测完把 CSV 路径回填到 ②③ 板对应行 |
| 文档不变量检查器 | 已编码 + 已单测 | `tools/check_doc_invariants.py` + 7 测试：把 AGENTS 第 2 条 b) 项变成一条命令；扫描范围按 09-22 定案**摘除规则自身行块**；退出码 0/1/2/3，**3 = 有文件没读到，此时"零命中"不算通过** | 无（每次改过编号就跑一遍） |

### ② 🔴 已编码但**必须上台架才算完**（全部用户侧，我代替不了）

| 编号 | 动作 | 通过标准 |
| --- | --- | --- |
| B1 | 烧录 `OBJ/PWM.hex` | 能启动、MANUAL 遥控正常 |
| B2 | 串口协议对拍 + H2 组合场景（**跑法：另开一窗 `python tools/bench_status.py`，边做边敲场景标记**） | ① MANUAL+失视觉→线上只有 HEARTBEAT；② AUTO+失视觉→NAV(0,0)+TOOL 提刀；③ 横移中切 AUTO→四轮角无 90° 残留；④ 断 SBUS **(a) 关接收机 (b) 线断悬空出乱码 两子情形都过** ≤500 ms 四轮停；⑤ SBUS 恢复→可继续手动；⑥ 连续 2 h 桥接无重复注入；⑧ 现场夺权（mode 切 MANUAL）后 PC 继续发 NAV + TOOL → 线上仍在发、刀具升降与横移均不动（F3） |
| B3 | 接线（含继电器板照片定刀控） | P0-7 闭环 |
| B4 | 三系数标定（Fw-1/2/3） | 百分表 / 卷尺反算 |
| B5 | 安全动作实测 | **属门 F**；全项通过才谈解除两条硬禁令的完整作业档 |
| B6 | 实物确认 5 项 | 看一眼就有答案 |
| B7 | RDK X5 上车 | 掉线 / 供电 / USB 短线 |
| B8 | 链路一票否决 | 控制帧往返 p95（**不是** `main.py` 感知 latency 列） |
| Hw-17 | 台架打印 `rec_sbus_data[33]` 三态值 | 正常 / 拔接收机 / 遥控器失联 |

> **B2 编号说明（一句话，别再展开）**：本表台架场景是 **①–⑥ + ⑧**，**故意跳过 ⑦**——
> ⑦ 属于下方"H2 关闭条件验收清单"里的**已知遗留 `send_angle`**，不是台架场景。
> 若把它当漏号补回本表，就会与那份清单抢号（09-22 已因此返工一次）。

| 编号 | 内容 |
| --- | --- |
| ⑦ 已知遗留 | MANUAL 失联只清 `veloc`，`send_angle` 仍保持最后转角：按"可接受"记录，**不许当作失联已完全仲裁** |

> **⚠️ 09-22 记录器实测定级（作者现场报：刀的电推杆没接在大板上；滑台伺服同样未接线）**
> 台架上**没有执行元件**，B2 这几条今天最多只能到"信号级"，不得勾成通过：
> ② 的"TOOL 提刀"、③ 的"横移中切 AUTO"、⑧ 的"刀具与横移不动"——三条都涉及刀/横移。
> 今天能拿到的证据是"线上帧的 `lift` 位与固件 PD4/5/6（T5 的 7/9/11）输出电平按指令变了"，
> 这证明固件动作，**不证明刀真的提起来了**；⑧ 的"不动"在无执行元件时是恒真命题，尤其不能算验过 F3。
> 行走/转向在车，所以 ①④⑤ 与四轮转角那条是真证据。**执行级留到接好推杆之后（门 F / P0-7 之后）再补。**

### ③ 🔴 明确**没做**（按谁能推动分三类，不含"部分完成"粉饰）

**A. 只能作者做 —— 要人或实物，不是代码问题**
- **【S1，本周】把控制栈装上上代车（3.25 m）跑通链路**：B1 → B2（含 SBUS 失联两子情形）→ 电脑能否控住、失联能否停车（台账 Hw-21、v1.0 §4.2）。软件模块与调试记录**可复用**，但"复用"≠"搬完不用测"：接线、执行方向、失联是否真停车、急停切断范围、供电与实测时延，到样机须**逐台再确认**
- **【S3 一次性事件】搬到真实车（样机在地里、不好运）前**：先断电逐项核对（48V 极性、共地、保险丝、刀梁锁定、急停切断范围），带备件（USB3.0 短线、保险丝端子、网线、便携电源、卷尺与地面标记签）
- **【门 N 现场项，只能在样机上做】补齐实测 + 机位标定**（量表 `docs/整车尺寸实测表_20260921.md`）：M3 行距、M7 刃宽、M8 滑台行程（**两端合计**）、M9/M10 提刀传动比与离地量、M11b 俯角、M12 相机纵向位置、M13 数刀头、**M14 胎面接地宽度、M15 轮迹对行线横向偏差**
- **【N1 未决】田块横断面**：轮距 191 ÷ 行距 30~40 = 4.8~6.4 个行距，只是"两轮之间跨几行"的算术，**推不出"轮下压过几行作物"**（反例：行距 38.2 cm 时 191 恰为 5 个行距，两轮正落在行间）。要判靠四项实测：轮迹偏差 / 胎宽 / 保护带 / 跟踪误差。**量出来之前文档与论文两侧都不许写"压苗"或"不压苗"**——这决定 V4 伤苗率分母
- **C1 秋采（10 月中前，全局最紧）**：预标注入口 `tools/启动预标注.bat` 可用，**默认不覆盖已有人工标注**（重做加 `--overwrite`）。**命名契约已定案**（09-22 作者授权 qoder 定）：一个条件一个目录、一次跑一个目录，文件名 `{批次}_{日期}_{序号}.jpg`；一组＝一段连续拍摄。旧 `IMG_0001.jpg` 会让分组键全是 IMG、240 张塌成 1 组（工具现在会拦并说明真因）；**已按旧命名拍过的素材要补改名**
- C2 标注与微调、C3 **样机机位外参（IPM）标定**（离地 100 cm；"低机位"是 `ch02:23` 的错措辞）、C4 SBUS 通道-速度映射表、C5 时延实测
- Hw-14 整车几何实测；Hw-11 伺服寄存器表核对；Hw-12 滑台接线；H4.7 只读仓 `chucao_prj` 脏树清理
- ② 整表

**B. 我能写代码，但被前置卡住 / 需要你点头开批**
- **H2.8 后半 + E3 整批**（F1/F2/**F3** 权限门、车辆档案握手与 STATUS 加字段、TELEOP、L0–L3）：动了就是改控制权限语义，须**作者批准 + zcode 审**。开工条件 09-21 后已成立（主线已合），**批准还没拿到**
- **H5.2 / E2⑤** IPM 接线：加载器与标定器已闭环，`perception.py` 仍占位、`load_ipm_params` **无调用方** → 链路未闭合
- **H5.3** 采集时间戳 / 帧龄拒绝（`rx_good/bad` 不能当丢包分母）
- **H5.4** 刀控 / 电流（返回 0）/ 电池（固定 48V）闭环 —— 等继电器板照片（P0-7）
- **H1.7** 分组清单冻结 —— 机制已有，等内容物（等 C1）
- **NAV2 / 4WS 帧** —— 前置门是 Hw-11 轮角反馈是否真可用
- **H3.3** eth0 换链路对端偶发挂死 —— 未查，怀疑同卡双网段
- **固件无构建标识 ⇒ "板上是哪一份镜像"不可读**（09-23 现场踩实）：`FRONT_AXLE_DIR_SWAP` 开/关两份 hex **Code 同为 44848、字节数同为 130,670**，只有文件 mtime 能区分；STATUS 帧里没有任何版本字段。后果不是不便而是**归因失效**——当天"改完没变化"的观察，实际是测在厂商原样那份上，白跑一轮。低成本解法（择一，均属协议/固件改动，要走审 + 五处同步）：① STATUS 的 `limits` 之外腾 1 字节做 build 序号；② 开机用现有 HMI 链路把编译日期时间上屏（不改协议）；③ 最省事的过渡办法：每次重编译把 hex 的 mtime 记进台账"认版"栏（今天已在用，但靠人记，不可靠）。
- **H4.4** `data_manifest.md` 绑定运行 ID —— 等 C1/C2 产物
- **H4.6** `DifferentialDrive()` 默认 `k_d=0.0` 且主入口未传（`control.py:86` 注释自认 P-only）→ deck 第 12 页"PD 加横向速率阻尼"是过度声明；论文侧不得继承，阻尼要么台架整定要么改述
- **`tools/bench_status.py` 只会收、不会发**：②⑧ 这类"PC 持续发 NAV/TOOL 的同时要看 STATUS"的场景，现在只能关掉记录器改开 `pc/main.py`（两者抢 9100），于是模式跳变/静默 gap/场景标记那条时间轴就丢了。补法约 20 行 + 4 测试：加 `--to <桥IP>:9000`（不填即彻底禁用发送，opt-in），stdin 里 `!nav v1 v2` / `!tool mm lift` / `!beat` / `!auto on|off` 直接出帧，并把**发出的每一帧也落进同一张 CSV**。今天没做是因为刀的台架没有执行元件、⑧ 本来就要降级，不是忘了

**C. 等对侧（zcode）**
- 当前待审（09-22 批次，条数请按 `git rev-list --count zcode/master..HEAD` 当场实测——写死数字必然落后于包含这句话的那条提交）：**spec 第三版、『📊 总览』整板重写、门 N 台架记录器、9100 端口冲突点名、X5 清单出门前跑法、Hw-1 现场事实批**
- 09-21 至 09-22 各批（E1、E2③④、撤回批、命名陷阱、spec 第一/二版、规则修订、检查器）**均已放行并入主线**；"等 merge"不再是阻塞项

### ④ 本批（09-22）**没碰**什么，避免被读成已处理
- **E3 未动**（③-B 第一条）；**P 区一行未改**（论文正文与 Word 仍是 `be9093a` + v14.docx，v1.0 §5 那 15 条是清单不是已完成）
- **台架 0 项**：没有任何一项从「已编码」升到「已台架」
- **主张边界 spec 的改单尚未执行**：v1.0 §2 本体一行未动（"V1 只作地点声明、两类量分两个数据集、S0 升回判据"等都还只是计划）；zcode 放行的是第二版，第三版待重看
- 组会 deck 工作树的改动是**汇报人自己的**，我未覆盖；下次动它先重读现文件
- `PWM.uvprojx` 第 40 行那个孤立 LF 仍未手工改（Keil 存盘会覆盖，别手改）；`PWM.uvguix.22763` 故意留脏不提交；`.gitattributes` 未加，等作者定

### ⑤ 等作者 —— 决策欠账（这块板过去只记工程欠账，不记这个）

| 等什么 | 卡住什么 | 备注 |
| --- | --- | --- |
| **主张边界 spec 批准**（三版，路径见 v1.0 §13 与本板 ④） | 该改单的全部实施：v1.0 §2/§4/§7/§8/§9 措辞、台账 Hw-22/Hw-23、采集清单矩阵、12 处一致性 | zcode 放行过第二版；第三版三处新修订需重看 |
| **E3 开批批准** | 控制权限那一批（含 F3）；秋季关键路径不靠它，但 H2 关闭靠它 | 不批就长期停在「已编码+已编译」 |
| **v1.0 方案本体审阅** | 现行方案自 09-16 起未过作者眼，而这三天被改了十几轮 | 至少读 §2（主张与 V1–V4）与 §4.1（两道门） |
| **试验田名称/位置**（作者 09-22："先记上，不填"） | 第 3 章与本数据集描述里的地点声明；凡需交代地点处统一引这一句 | 只有作者能填；填前 spec 内保留〔〕占位 |
| 现场动作 | 见 ② 与 ③-A | B1/B2 是 H2 关闭唯一剩余途径；记录器已就位（`tools/bench_status.py`） |
---

## A. 已完成 ✅（代码侧，全部有测试或编译验证）

| # | 交付物 | 验证方式 |
| --- | --- | --- |
| A1 | `common/protocol.py` 帧协议（CRC16-CCITT-FALSE / 收发 / 流式拆帧 `extract_one`） | pytest 10 例，标准向量 0x29B1 |
| A2 | `pc/perception.py` 感知链：懒加载标定→去畸变→DeepLabV3+→IPM→双墙→远/近场中心线 | 训练域测试图 status=dual，中心线贴合 |
| A3 | `pc/replay.py` 离线回放框架 + CSV 日志 + 叠加图 | 训练域图回放通过；日志字段齐全 |
| A4 | `pc/control.py`：中间刀 PID（条件积分抗饱和）、时延补偿（p50/p95）、差速运动学 vL/vR、横向速率估计 | pytest 8 例，阶跃 300ms 稳态 ≤1mm |
| A5 | `pc/state_machine.py` 四状态安全机，ESTOP 锁存仅物理复位可解 | pytest 4 例 |
| A6 | `vehicle/bridge.py` UDP↔UART 桥 + 500ms 看门狗（逻辑与 I/O 分离） | pytest 4 例（看门狗时序边界） |
| A7 | `vehicle/stream_pi.py` + `config.yaml`（720p25 H.264/RTP 管道） | 代码审查（无 Pi 无法运行验证） |
| A8 | `firmware/protocol.c/h` + `retrofit.c/h`（UART6 链路/双指令源/刀控联锁/500ms 看门狗/TIM4 步进/TIM3 轮速捕获/20Hz 状态帧） | **Keil 0 错误编译通过，Code=44192 B** |
| A9 | 固件完整集成：main.c 挂 retrofit_init；TIM6 1ms 时基；telecontrol.c SBUS 心跳；car_control.c Out_Pwm AUTO 注入；旧 USART6 调试口让位 | 同上，hex 已生成 |
| A10 | `common/uart_vectors.py` 8 组对拍向量（含 2 组必须拒绝的坏帧） | 本机运行输出核对 |
| A11 | `docs/refs/参考资料调研.md`（王硕博士论文 + 李俊硕士论文 + 4 个开源项目，含章节页码级引用建议） | 文档在库 |
| A12 | 调试实证 4 条（可写进论文）：抗饱和实现不当→积分器卡死；执行滞后+原始微分→振荡；去畸变先缩放后 remap→四分之一画面 bug；zip 旧 OBJ→假链接冲突 | 全部有复现过程 |

---

## B. 🔴 硬件在场才能做（全部用户侧，顺序执行）

### B1. 烧录固件 🟢 **已解锁**（09-14 编译门槛 0 错误达成，等你接板子）
- **做什么**：把新生成的 hex 烧进大板（J-Link/ST-Link 或串口 ISP）。
- **hex 实际位置（09-14 实测核对，非 `USER/OBJ/`）**：`firmware/大车proj/大车/OBJ/PWM.hex`（130,641 B，随本轮 `ef7d905` 重生成；axf 同目录）。
- **怎么做**：Keil 里 `Flash → Download`，或 STM32CubeProgrammer 烧上面那个 `PWM.hex`。
- **验收**：上电后行为与烧录前完全一致（底盘遥控可开、刀继电器不动）——retrofit 只初始化不干预，MANUAL 是默认态。**注意本轮起 MANUAL 多了 SBUS 失联保护：烧完后若摇杆完全不动，先确认接收机已通电且能收到有效帧（⑤ 恢复可控），再判断是否接线问题。**
- **耗时**：10 分钟。**依赖**：无（编译依赖已满足）。

### B2. 串口协议对拍 🔴（固件bring-up 第一关）
- **做什么**：USB-TTL 接 STM32 的 USART6（板 PC6=TX→TTL RX，PC7=RX→TTL TX，共地），PC 发 8 组向量验证解析。
- **怎么做**：`python common/uart_vectors.py COM口`（自动循环发）或 `--dump` 手动灌。USB-TTL 若未采购见 E2。
- **验收**：① 6 组有效帧被正确执行（用心跳+导航帧即可观察：发 nav_straight 时若强制 AUTO 才动作，可先只验证"收到不崩+状态帧 20Hz 出现"）；② `bad_crc_must_reject` 和 `truncated_must_reject` 被静默丢弃（无任何异常动作）；③ PC 端能收到 0x10 状态帧（可用 `python -c` + pyserial 抓打印验证 CRC 通过）。
- **耗时**：1-2 小时（含接线）。**依赖**：B1、USB-TTL×2。

### B3. 接线（按 v0.7 §13.2 引脚表）🔴
| 连接 | 引脚 | 注意 |
| --- | --- | --- |
| USART6 → 树莓派 UART | PC6/PC7 ↔ Pi GPIO14/15，**共地**，Pi 侧 3.3V 电平直连（PC6 输出 3.3V，无需转换） | 树莓派 UART 默认给蓝牙，需在 config.txt 分配（见 B7） |
| 刀继电器 ×3 | PD4/PD5/PD6 → 外接继电器模块输入（74HC245 已升 5V，高有效） | 继电器模块建议光耦型，独立供电 |
| 中间刀步进 | PB6=脉冲 PB5=方向 PB7=使能 → 驱动器对应输入 | 共阳/共阴接法按驱动器手册；驱动器细分数记录下来算系数 |
| 限位开关 ×3 | PD15(原点)/PD10(左)/PD11(右)，开关接地，内部上拉，闭合=低 | 常闭型优先（断线即触发） |
| 急停回路 | 确认 PA5/PF10 现有接线（B6 ①②）后决定是否串入 | 保持常闭硬线原则 |
- **验收**：万用表逐点量通断；上电后限位开关状态能从 0x10 帧的 limits 字节读出（触发位翻转）。
- **耗时**：半天。**依赖**：B1；树莓派部分依赖 B7。

### B4. 三个系数标定 🔴（台架）
| 系数 | 位置 | 做法 | 验收 |
| --- | --- | --- | --- |
| `STEPPER_STEPS_PER_MM` | retrofit.c:15，当前 25.0 | 滑轨装好后：发 tool 帧 ±20mm，百分表量实际位移，反算；驱动器细分数改变时重标 | 10 次往返重复定位 ≤0.5mm（v0.4 §5.4） |
| `c_per_pulse`（轮速） | retrofit.c wheel_speed_update，当前 0.0005 | 顶起车轮，手转整 N 圈，对比 PC 收到的速度积分路程；或拖行 10m 实测 | 误差 ≤5% |
| AD5 电流换算 | retrofit.c `adc_current_a()`（当前返回 0 占位） | 万用表串入电机回路对照 AD5 读数线性拟合；把读取代码接到 iic.c 的 ADS1115 U18 通道 | 误差 ≤0.2A |
| SLEW_ACC 斜坡斜率 | retrofit.c:15，当前 0.2 m/s² | 阶跃切 AUTO 观察：斜率过大→仍窜车；过小→响应滞后（横向纠偏超调）。从 0.1/0.2/0.4 三档试，选定后记入论文标定表 | 切换瞬间轮速无可见跳变且纠偏超调 ≤20% |
- **做法细节**：`adc_current_a` 接线参考 `iic.c` 中 U18（I2C2，PB10/PB11）已有的读法，读 AD5 通道原始码 → 电压 → 按 ACS712-05B 灵敏度 185mV/A 换算，减去静态偏置。
- **耗时**：各 1-2 小时。**依赖**：B2（链路）、B3（机械件）。

### B5. 安全动作实测 🔴（整车台架，对应 v0.4 §8.2）
- **做什么**：逐项验证安全清单。怎么做与验收：
  1. **心跳超时**：进入 AUTO（遥控+PC 同时在线）→ 拔 USART6 线 → 车必须 500ms 内停 + 提刀。 stopwatch 实测（手机录像 240fps 数帧）。
  2. **坏帧注入**：发 `bad_crc` 帧 → 无任何动作。
  3. **ESTOP 锁存**：发 estop 帧 → 之后任何 nav/tool 帧无效 → 按物理复位（接 PD 上按键调 `retrofit_clear_estop`，或重上电）才恢复。
  4. **硬件急停**：按板上急停钮 → 驱动断电 ≤50ms（录像数帧）。
  5. **限位触发**：手挡中间刀滑轨限位 → 0x10 帧 limits 位翻转 + 步进停。
- **验收**：全部留视频/照片存 `hardware_ref/log/`（论文安全章节证据）。
- **耗时**：半天。**依赖**：B2、B3、B4。

### B6. 实物确认 5 项 🔴（看一眼就有答案，尽快做）
1. PA5 大继电器（SLA-05VDC）实车接的是什么？→ 决定硬件急停切哪路电
2. PF10 主继电器线圈回路的 NBREAK2 端子现接什么？→ 是否急停串入点
3. SBUS 各通道→四轮速度映射：固件加打印或看 led.c 里 switch_ch 用法，列成表发我（AUTO 指令量纲对齐用）
4. 遥控器有无空闲两段开关 → AUTO/MANUAL 切换判据（没有就用通道组合）
5. ~~485 页 U7（PC6/PC7 的 MAX13487）是否不贴/无外设~~ → **🟡 09-22 现场：U7 已贴且 TTL/485 两颗选型 0R 都贴了 ⇒ 485 支路没被旁路**（台账 Hw-1）。剩下的不是"看"而是"量"：X5 TX→大板 PC7 这根线上 RO 有没有在抢（判据与三档处置见接线图 §7）。若确认对顶，"换链路串口"就是**改设计**，要走 zcode 审，不许现场偷偷飞线绕过
- **耗时**：1 小时拍照+记录。**依赖**：无，**本周就做**。

### B7. 树莓派上车 🔴 → **已改由 RDK X5 执行**；✅ 09-10 X5 单板验机四项全过（烧录/SSH/UART ttyS1/推流 TCP-MJPEG 105ms@30fps，见 docs/X5验机与接入执行清单.md）。剩余：上车接 STM32 + 网桥换网线重测时延
- **做什么**：~~Pi 4B/5 刷 Bookworm~~ → **X5 烧 Ubuntu 22.04（Rufus）→ 网线直连 SSH（eth0 静态 192.168.127.10，PC 设 192.168.127.100）→ UART 用 40pin Pin8/10（UART1，3.3V，/dev/ttyS*）**。完整步骤/命令/验收见 **`docs/X5验机与接入执行清单.md`**（含 E2.2 到货当天四项验机：烧系统/SSH/推流/UART）。
- 车端配置差异：`vehicle/config.yaml` 的 `serial_dev` 用 `/dev/ttyS1`（以板上 `ls /dev/ttyS*` 实测为准），其余（stream_pi.py、bridge.py）不变。
- **验收**：PC 屏上出实时 720p 图，端到端时延（拍秒表对比法）<100ms。
- **耗时**：半天。**依赖**：E2 ✅ 已到（X5、USB-TTL×2、网桥）。

### B8. 链路一票否决测试 🔴（v0.4 §6.1 硬门槛）
- **做什么**：真实田间距离 120m：PC 开 5GHz 热点，Pi 连接，ping 100 包 + 控制帧打流 10 分钟。
- **验收**：丢包 <1%，控制帧 p95 时延 <50ms。**不达标 → 装 E4 的定向天线重测，直至达标才准进 M2**。
- **耗时**：1 小时。**依赖**：B7。

#### B8-预测量（2026-09-15，台架近距离，网桥在链路中）——**这不是 B8 验收**
- 拓扑：PC 以太网 192.168.127.100 →〔PC 端 CPE ←5GHz→ 车端 CPE〕→ X5 192.168.127.10。
- **X5 可达**：SSH(22) connect 3.0 ms 有应答；主机密钥为**新添加**（说明这台 X5 与 09-10 验机时的 host key 不同，可能重烧过系统，下次登录留意）。
- **网络 RTT 实测**（H2.9 四项里的**只有这一项**，其余三项未测）：
  - 32 B 载荷 ×30：**0 丢包**，1–2 ms
  - 1472 B 满包 ×100：**0 丢包 / 0 挂死**，min 1 / median 4 / mean 6.5 / **p95 17** / max 21 ms，stdev 5.6
- **观察**：32 B 载荷 1–2 ms，1472 B 满包 p95 17 ms、14–17 ms 长尾 35/100。**推断（未证实）**：时延随包长增长符合共享无线介质特征，故"网桥在路径上"的可能性大；**但这不是证明**——要确认拓扑需查现场接线、路由表与两端设备状态（09-21 复审指出我把这句写得比证据强）。
- **观察**：TCP 22 有应答、5000 连接**超时**。**推断（未证实）**：X5 上 `stream_pi.py` 未启动；注意"没人监听"通常立刻返回 refused，超时更像被丢弃/防火墙或主机未响应，故**不能据此断定推流进程状态**（09-21 复审指出）。因此**视频同框时延这项今天没测到**。
- **H3.3 未复现**：本轮无"换链路后对端挂死"；但该故障需要**切换链路**才触发，纯 ping 复现不了，仍列为未查。
- **B8 仍然算未做**，缺的是：120 m 实距、控制帧打流 10 min、以及 p95 <50ms 的**控制帧往返**口径（满包 ICMP 不能替代）。

---

## C. 🔴 数据/标定（算法质量类，多数可并行启动）

### C1. 秋季图像采集（**时间最紧，10 月中前必须完成**）
- **做什么**：按采集清单（D4，我下周下发）在田间拍 200-300 张 + 3 段新视频。
- **为什么紧**：avi 帧域差异已实测证实（过分割 fg≈0.55，双墙提不出）——现有权重在当前田间图像上不可用，不补数据 M2 的"感知回放通过"里程碑必跳票。
- **做法**：等 D4 清单（内容：机位/角度/光照矩阵、分辨率、命名规范、每类最少张数）。
- **验收**：清单覆盖率 100%，图像入 `D:\ai work\zcode\autumn_data\raw\`。
- **依赖**：无（现在就能拍，趁草还绿着）。

### C2. 标注与微调 🔴
- **做什么**：labelme/多边形标注（我出规范）→ 与夏季数据混合 → `DeepLabV3Plus-Pytorch-master` 微调 best_model.pth（可上 Colab 免费卡）→ avi 留出段 + 新视频回放复测。
- **验收**：新视频回放 status=dual 比例 ≥80%，中心线肉眼贴合；mIoU ≥0.75。
- **耗时**：标注 2-3 天 + 训练 1 天。**依赖**：C1。

### C3. 样机机位外参（IPM）重标定 🔴

> 口径（09-21）：相机离地 **100 cm**（Hw-20 现场确认），`ch02:23` 的"低机位"是错措辞，别再拿它当装机要求。轮心才离地 30 cm。
- **做什么**：相机装上 0.9m 机位后，田面/水泥地摆 40/50cm 标记点 → 拍图 → 重推 IPM_SRC 梯形与 m/px 比例 → 改 `pc/perception.py` 的 IPM_SRC/IPM_SCALE_X/Y。
- **做法**：棋盘格内参沿用 calib_params.npz；IPM 用地面 4 点单应即可（我会写一个 `pc/calib_ipm.py` 一键算）。
- **验收**：3 个标记点投影误差 ≤2cm（v0.4 §5.6）。
- **耗时**：1 小时拍摄 + 我 2 小时计算。**依赖**：相机支架装好。

### C4. SBUS 通道-速度映射表 🔴
- **做什么**：B6③ 的表 → 我把 `retrofit.c` 的量纲换算核对/改写。
- **验收**：AUTO 模式下发 vL=vR=0.14，车实际走 0.5km/h（GPS 或秒表量 10m）。
- **依赖**：B6、B2。

### C5. 时延实测 ⚪（链路通后自动积累）
- **做什么**：LatencyCompensator 已内置 p50/p95 统计；链路通后跑 10 分钟积累，写入 `results/latency_log.csv`。
- **验收**：p95 <50ms（与 B8 一致性检查）。
- **依赖**：B8。

### C6. ⚪ 错误帧回归集（可选）
- 把台架发现的任何异常帧存成回归用例，加入 `tests/test_protocol.py`。
- ✅ 09-05 协议健壮性核实结论（全部有测试覆盖或核实无风险，无需改动）：① `extract_one` 对长度非法/CRC 失败均逐字节重同步（`tests/test_control.py` corrupt 用例覆盖）；② 最大帧 521 字节，bridge `recvfrom(2048)` 余量充足；③ seq 掩码是调用方纪律（pc/main.py、bridge 均已 `& 0xFFFF`；pack_frame 超范围直接 raise，保持 fail-fast）；④ `unpack_status` 等定长校验抛 ValueError——接收侧实现时必须接住，见 D7。

---

## G. v0.7 方案旧路径勘误（2026-09-05，工作区整合后）

> v0.7 docx 交付矩阵写于整合前，以下路径已迁移；**资产位置以根目录 README.md 为权威**，v0.7 相应章节按此对照。下次出 v0.8 时一并修正。

| v0.7 写的旧路径 | 现位置 |
| --- | --- |
| `prj_xiangjibiaodi/相机标定工程/calib_params.npz` | `data/calib_params.npz`（加载方：`network/camera_calib.py`、`pc/perception.py`） |
| `avi_project/3 段田间作业视频 field_video1~3.avi` | `data/videos/`（已 gitignore，仅本地） |
| `avi_project/295 帧抽帧 frames1` | `avi_frames/`（已 gitignore） |
| 根目录 `morph_process.py`（peony_postprocess / extract_dual_walls 等） | `tools/morph_process.py`（pc/perception.py、network/local_single_station.py 引用，两侧 sys.path 已加 tools/） |
| `chucao_prj/model_data/` 数据集/权重 | `model_data/weights/best_model.pth`（本仓库内，路径未变） |

另：v0.7 中 bridge "naive stream split" 描述已过时——串口跨读边界丢帧缺陷已修复（abde261，`poll_serial_frames` remainder 缓存 + 4 个重组测试，34 例全过）。

---

## D. 🔴 我侧待写（下一批交付，均已排好）

| # | 交付物 | 内容 | 预计 |
| --- | --- | --- | --- |
| D1 | ~~`pc/main.py` 主循环~~ ✅ 09-02 | 回放/实车双模式，含 ESTOP 横向超限联锁（实测 -0.12m 触发）、心跳维持、CSV；3 帧冒烟通过 | — |
| D2 | ~~监控面板~~ ✅ 09-02 | 并入 main.py：分割叠加+HUD+按键 [A]uto/[M]anual/[E]stop/[R]eset/[Q]uit | — |
| D3 | ~~秋季采集清单~~ ✅ 09-02 | ：拍摄矩阵/内容要求/命名规范/标注规范 | — |
| D4 | ~~`pc/calib_ipm.py`~~ ✅ 09-03 | grab/pick/solve 三步流程，合成数据自测：0.8px 噪声下重投影误差 5.9mm（验收线 2cm） | — |
| D5 | ~~方法章理论材料~~ ✅ 09-02 | ：三块推导+式号+代码出处对照+答辩三问预演 | — |
| D6 | ⚪ 固件 C 桌面测试 | protocol.c 编译成 DLL 与 Python 对拍（台架 B2 已覆盖，可暂缓） | 0.5 天 |
| D7 | ~~`pc/main.py` 增加 STATUS 接收（实车模式）~~ ✅ 09-09 代码完成 | **已实现**：`pc/status_rx.py` `StatusReceiver`（纯逻辑类，6 个测试 `tests/test_status_rx.py` 全过）+ `pc/main.py` live 模式绑定 UDP 9100 非阻塞收包（`drain_status`，replay 模式不建 socket）。坏帧整体包 `try/except ValueError` 计数不裸抛；滚动 1 秒 ≥5 坏帧 print 报警（协议字段失同步提示）；HUD 显示 MCU 模式/电压/电流/坏帧数；CSV 增加 mcu_mode/batt_v/rx_good/rx_bad 四列。背景：bridge 已把 STM32 帧经 `extract_one`（CRC 校验过）逐包 UDP 转发到 PC_PORT 9100；串口跨读边界重组已在 bridge 修复（abde261，`poll_serial_frames`）。剩余：实车联调验证（随 B7/B8） | 联调即验 |

---

## E. 外部依赖

| # | 项 | 状态 | 动作 |
| --- | --- | --- | --- |
| E1 | ~~git push~~ | 🟢 已恢复并推送（5fc9177），后续每次交付自动推 | — |
| E2 | 采购清单（2026-09-03 细化，含用途与参考价） | 🟡 用户已确认电推杆/继电器已有（现遥控器直控，未接 MCU） | **本周下单**（影响 B2/B3/B7 全线） |
| E2.1 | USB-TTL ×2（CP2102 款，带 3.3/5V 跳线） | ¥10-15/个 | B2 串口对拍必需 |
| E2.2 | ✅ 已选型（09-03 比价）：**RDK X5 基础套餐 4GB，¥1015**，大菠萝数码专营店（天猫 4.8 分）。含 64G 卡+散热片+读卡器+电源+Type-C。不选 8GB（负载用不满）；不选单主板/简配（缺散热必降频）。⚠️ 该店不支持 7 天无理由——**到货当天验机**：烧系统→SSH→推流→UART 四项全过再放。适配由 ZCode 负责 | ¥1015 | B7 车端网关；未来边缘推理零二次采购 |
| E2.3 | ~~NEMA17 驱动器 TB6600~~ | ❌ 09-05 取消：中间刀实为伺服+丝杆滑台（车上已装未接线，Hw-12），无步进可驱，不必购买（影响 B3 中间刀） | — |
| E2.4 | 5.8G 室外 CPE 网桥 **一对**（COMFAST E110A/E312A 类，点对点桥接）：PC 网口↔车端树莓派网口，免驱动 | ¥300-500/对 | B8 链路一票否决；比 USB 定向网卡可靠 |
| E2.5 | 光耦继电器模块 ×3 → **✅ 09-05 基本取消：电推杆已在车上、由现有外接继电器板控制**。剩一步：拍继电器板照片——①路数（双向换向需 6 路或板内已有换向逻辑）②输入触发极性/电平③现有触发源（遥控器还是原控制器），据此决定我们 6 路输出并联接入还是需切换电路 | ¥0 | 拍照发 ZCode 判读 |
| E3 | 弹齿刀采购 | 🔴 未下单 | 本周下单（对比试验刀头，W10 前到即可但不冒险） |
| E4 | 5GHz 定向天线/室外 AP | 🔴 未下单 | B8 不达标时的救命件，建议随 E2 一起买 |
| E5 | 导师认可创新点表述（v0.7 三点式） | 🔴 未沟通 | 下次见导师带上 v0.7 §7 |
| E6 | 田块协调（秋季除草作业许可） | 🔴 未确认 | 拍 C1 样本前就要落实 |

---

## 建议执行顺序（本周，09-05 复核）
1. **用户**：B6 实物确认（1h）→ E2/E3 下单 → B1 烧录 → B2 对拍（顺序不变：D1/D2/D3/D5 已完成，用户侧硬件链路仍是唯一阻塞）
2. **我**：无待写交付排队；D7 代码已完成（09-09），剩实车联调验证（随 B7/B8）
3. **并行**：C1 秋季样本现在就能拍（草还绿，每拖一周域差异风险越大）

---

## F+. P0 安全整改（2026-09-04，响应第二次外部审查）

> 审查证实三处 P0：① 安全门控补丁打在未被编译的 car_control.c 上，真实驱动路径（main.c pwm_veloc）无门控；② PC 急停/降级从不发 ESTOP 帧，固件把心跳当链路存活；③ 双 IWDG 并存。均已修复并重编译（Code=44544，0 错误）：
> - P0-1：门控移入 main.c 驱动点——AUTO 用 retrofit 斜坡轮速，ESTOP 四轮强制 0，MANUAL 原路径不变（含 retrofit_mode 补上缺失的函数体）
> - P0-2：pc/main.py 在进入 ESTOP/LIFT 的状态迁移瞬间显式发送 TYPE_ESTOP 帧（一次），固件锁存
> - P0-3：删 retrofit 重复 IWDG（见 F2 行）
> - P1 同批：限位开关→步进停（PD15 原点保持/PD10/11 方向闭锁）；MANUAL 刀默认提刀（TOOL 帧 500ms 新鲜度）；bridge 看门狗只在"PC 60 秒内活跃"时注入 ESTOP（纯遥控不被锁死）；图传改 MPEG-TS（OpenCV udp:// 可解码）；删除陈旧 firmware/大车/ 拷贝

## F++. 接线图与参数差异台账（2026-09-05）

- **`docs/接线图_v1.md`（v2 整车版）**：全车元件接线图（电源/行走/转向/作业/控制/人机六大系统），RDK X5 化。⚠ 接线前必查：① RDK 须独立 48→5V/4A 供电，严禁挂大板 5V 轨（§1-P5）；② PC6/PC7 兼接 485 收发器 U7、TTL 引出点待万用表敲定（B6-5）；③ T5 刀继电器脚号 7/9/11 有 ±1 行推断风险；④ PB5/PB6/PB7 步进引出点原理图未列出，可能需飞线；⑤ SL1 只断 MOTOR_1，后轴急停覆盖缺口待评估。**上电前先过其 §7 检查单**。
- **`docs/参数差异台账.md`**：实车与固件/PC 参数出入的统一登记处（Fw-1~10 / Pc-1~6 / Hw-1~7），含测法与验收线。**改参数一笔记一笔**；与 B4 台架标定互为索引。已登记：E2.2 车端改 RDK X5（Hw-6）、E2.3 步进驱动器 TB6600（Hw-7）。

## F* 第三次外部评审裁决（2026-09-05，8 条 P0 抽验 8/8 成立）

> 结论采纳：**当前禁止实车 AUTO、禁止按现有接线文档直接带动力接线**。评分 3/10 的判定"模块已写完≠系统已完成"成立。逐条实测裁决：

| # | 指控 | 验证证据 | 状态 |
|---|---|---|---|
| P0-1 | 论文按滑移转向建模，实车有四轮转向伺服 | docs/决策依据说明.md D8 写"实车没有转向轮偏转执行器"，与实车/固件(main.c:515 send_angle)矛盾 | 🔴 论文模型与 D8 决策须按实车重写（四轮转向+差速混合） |
| P0-2 | **STM32 永远进不了 AUTO** | ✅ 09-05 修复：NAV 语义=进入 AUTO（去掉 MANUAL 拦截）；HEARTBEAT=PC 存活但未指令→回落 MANUAL（遥控恢复）；协议显式模式字段留作 D 级增强 | 🔴→🟢 代码已改，✅ 已重编译(09-08,0 错误,61 警告均为遗留,Code=44616) |
| P0-3 | 在线推理归一化漏 /255 | ✅ 09-05 修复：抽出 preprocess_rgb() 强制 /255（tests/test_perception_norm.py 2 例）；F5 真实图像测试随之暴露 morph_process:302 除零，已加空墙回退 | 🔴→🟢 已修 |
| P0-4 | 视觉丢失/按键急停不发 ESTOP 帧 | ✅ 09-05 修复：prev_state 提前到帧首；键盘 E 路径补发 ESTOP 帧 | 🔴→🟢 已修 |
| P0-5 | 桥接冷启动锁死纯遥控 | ✅ 09-05 修复：last_pc=0 初始化（tests/test_control.py 3 例：冷启动不注入/见帧后超时注入/窗口过期停止） | 🔴→🟢 已修 |
| P0-6 | printf 污染协议帧 | ✅ 09-05 修复：usart.c fputc 置空（GBK 文件按 GBK 修补），集成说明"printf 让位"此句终于属实 | 🔴→🟢 已改，✅ 已重编译(09-08,0 错误,61 警告均为遗留,Code=44616) |
| P0-7 | 上电首 500ms 刀全落（判"新鲜"但 lift_bits=0）；ESTOP 不驱动 PA5；3 GPIO 不能完成 6 路换向 | apply_outputs 初值逻辑实测确认 | 🔴 与 Hw-9/9a 继电器板接入方案一并重做刀控 |
| P0-8 | 回放可误驱实车 | ✅ 09-05 修复：sock 仅 live 创建，replay 下 send() 为空操作 | 🔴→🟢 已修 |
| P1-1 | STATUS 无 PC 接收端（D7） | 已知未做 | 🟡 原 D7 计划 |
| P1-2 | STATUS 假数据（电流 0/电池 48.0 固定） | 已知（Fw-4/5）；U17 已确认贴片，具备接真条件 | 🟡 接 U17/U18 |
| P1-3 | tool_offset_px=None 崩溃 | ✅ 09-05 修复：AUTO 分支 None→0 | 🔴→🟢 已修 |
| P1-4 | RDK 未适配（stream_pi/ttyAMA0） | 已知（Hw-6） | 🟡 到货适配 |
| P1-5 | IPM 标定未接入运行时；5.9mm 是拟合误差非独立验证 | 已知（Pc-1）；"独立验证误差"批评采纳，标定后须用第 5 个点验证 | 🟡 C3 时做 |
| P1-6 | 时延只统计推理；视频无"只取最新帧" | 采纳；F3 分段打点已排期，最新帧机制补入 main.py | 🟡 |
| P1-7 | train_m.py 写死原仓库路径 | ✅ 09-05 修复：数据路径改为工作区相对解析 | 🔴→🟢 已修 |
| P1-8 | 桥不校验 UDP 来源/内容，垃圾帧可维持看门狗 | 采纳；帧 CRC 校验已在 bridge 转发前做，但"收到即续命"仍掩盖失联；改为仅 NAV/HEARTBEAT 有效帧续命+来源过滤 | 🟡 |
| 文档 | v0.7 DOCX/组会 PPT 与现状冲突；接线图 T5 三路=伸出/缩回表述过时 | 采纳：v0.7 降级为历史版本；PPT 6/15/16 页汇报前必须改；接线图 §4 已按外接继电器板方案更新，再复查一遍 U17/18、PD15 表述 | 🟡 |

**修复批次建议**（待用户点头即执行）：①10 行级速修 P0-2/4/5/6/8+P0-3+P1-3/P1-7（半天，全带回归测试）；②刀控/继电器板接入设计（等照片）；③论文/PPT 文档同步（等①完成后按新事实重写）。

## F. 外部评审采纳项（2026-09-03，另一 AI 评审筛选后采纳）

> 原评审 12 条批评，判定：采纳 5、简化 3、已覆盖 3、不采纳 1（IPM 在线倾角估计——过度工程，理论材料 4.x.3 的误差分解表为其边际收益提供反证）。完整判定记录见会话记录，此处只列进账。

| # | 采纳项 | 落点 | 优先级 |
| --- | --- | --- | --- |
| F1 | ~~指令斜坡过渡~~ ✅ 09-03 已实现并编译通过（SLEW_ACC=0.2 m/s²，1ms 步进，急停目标强制 0） | 固件 | — |
| F2 | ✅ 09-04 整改：撤销 retrofit 内重复 IWDG（同外设不可双实例），保留并依赖 main.c 原有 IWDG（1s，主循环喂）——retrofit/TIM6 若锁死主循环停喂同样触发复位，覆盖成立；复位后默认 MANUAL | 固件 | — |
| F3 | **时延分段打点**：协议状态/视频帧加 t_capture 字段，拆分 采集→传输 / 推理 / 执行 三段，分级前馈 | pc/ + common/protocol.py 载荷扩展 | 🟡 中（W4 链路通后） |
| F4 | **电机电流→刀具扰动前馈**：ACS712 电流作阻力观测，刀具 PID 加前馈项；做好了升级创新点 2 表述 | pc/control.py + 固件电流上报 | 🟡 中（台架后） |
| F5 | ✅ 09-03 实现，**09-04 按审查整改数字**：行投票裁剪 LSQ + 门控权重已接入生产管线（pc/perception.py，NaN 防护）。可复现数字（tests/test_adaptive_walls.py）：确定性稠密遮挡算例 25.5→0.5px；随机坡度套件 2.1→1.6px（仅裁剪贡献）；**真实掩膜 + 60×30 blob 模型下中点法本身仅 0.2px 误差（薄墙+LSQ 天然鲁棒），加权无必要也无害**。创新点 1 表述以确定性算例为量化证据，如实区分场景 | tools/morph_process.py, pc/perception.py, tests/ | — |
| F6 | 田间环境防护 checklist：镜头防尘罩、电路板三防漆、电机电源 EMI 磁环——并入 E2 采购与装配清单 | 硬件 | 🟡 中 |
| F7 | 试验设计修订：核心组（主动vs固定）5 趟重复，刀具组 3 趟；全部 ANOVA；CSV 增加草密度目测分级字段作协变量 | M4 试验执行 | 🟡 中（W10 前） |
| F9 | 对齐开题承诺（2026-09-05 读开题报告后补）：开题 2.3 承诺"霍夫变换 vs 最小二乘拟合对比试验"——将 F5 消融扩展为三方对比（Hough vs 朴素LSQ vs 行投票裁剪），离线即可完成，写进论文 4/5 章 | tests/test_adaptive_walls.py | 🟡 中（离线，随时可做） |
| F10 | 论文叙事锚点=开题四部分研究内容（平台与装置/导航线提取/解耦控制/田间试验），已逐项对应；两处调整（林下→大田、4WS→差速）已在组会 PPT 第 5 页主动说明 | 论文第 1-2 章 | — |
| F8 | 不采纳备案：IPM 在线倾角估计（过度工程）、硬件过流比较器（剪切销+软件阈值已双保险）、BiSeNet 备份（写展望） | 论文"不足与展望"章节素材 | — |

## F** 第四轮复核后的第二批修复（2026-09-05，评审 8 项阻塞中 5 项闭环）

| 阻塞项 | 修复 | 验证 |
|---|---|---|
| #2 上电前 500ms 刀全落 | retrofit.c：`last_tool_ms==0` 视为"从未收到 TOOL"，MANUAL 默认走提刀分支（两份拷贝） | ✅ 已重编译(09-08,0 错误,61 警告均为遗留,Code=44616) |
| #4 ESTOP 无物理断能 | retrofit.c `retrofit_poll_1ms`：锁存期间每 1ms 强制 `SW_Stop=0`（PA5→SL1 断 MOTOR_1 24V=刹车），压制原车主循环的松刹写入；**注意 SL1 仍只覆盖 MOTOR_1，后轴断能缺口待评估** | ✅ 已重编译(09-08,0 错误,61 警告均为遗留,Code=44616)+台架实测 |
| #5 AUTO 转向未接管 | main.c 门控 AUTO 分支强制 `angle[0..3]=0`（经各轮 correct=标定直行位）；遥控摇杆不再影响 AUTO（Fw-11） | ✅ 已重编译(09-08,0 错误,61 警告均为遗留,Code=44616)+台架定方向 |
| #6 LIFT 与 ESTOP 语义冲突 | pc/main.py：进入 LIFT 不再发锁存 ESTOP，改为持续 NAV(0,0)+TOOL(lift=0x07)——MCU 保持 AUTO 零速提刀、可恢复；PC 彻底失联仍由看门狗锁存；ESTOP 帧只留给横向超限/按键急停 | pytest 42/42 |
| #8 桥不校验 UDP | bridge.py 新增 `valid_frame()`：CRC 不合法帧既不转发也不喂看门狗（垃圾/伪造报文无法掩盖失联） | pytest 2 例（合法帧通过/垃圾与坏 CRC 丢弃） |

**仍未阻塞解除（依赖外部）**：#1 Keil 重编译（用户侧，编译后需重验 0 错误）；#3 继电器板照片；#7 STATUS 接收/真数据/RDK/IPM（D7/台架/C3/到货）。**带动力上车前置条件：Keil 重编译 0 错误 + 继电器板照片判读 + B2/B5 台架安全项全过。**

## F+* 第五轮复核修正（2026-09-08，评审指出 866572b 三处高估，均已返工）

| 评审指出 | 返工内容 |
|---|---|
| 转向接管位置错误（写在 send_angle 之后、被 path_plan 覆盖） | ✅ 移除门控内的死代码，接管改为紧贴 send_angle(4,...) 之前执行——AUTO 下四轮角度强制直行后再下发 |
| SW_Stop 1ms 强制仍有竞态（原主循环两个 tick 之间可写高） | ✅ 三处原车 `SW_Stop=` 写点全部加 `if (!retrofit_estop_latched())` 门控；1ms 强制保留为双保险；新增 `retrofit_estop_latched()` getter（retrofit.h/.c 双份） |
| 上电 PD4/5/6 未立即置安全电平 | ✅ retrofit_init 显式拉高三路（提刀），不等首个 1ms poll |
| bridge 仅 CRC 校验（合法帧可带尾随字节、无来源认证） | ✅ valid_frame 加精确长度校验（带尾随字节的整包拒绝）；config.yaml 新增可选 `allowed_sources` IP 白名单；+2 测试 |
| 刀具/继电器六路互锁与极性 | ⏳ 仍等继电器板照片（#3） |
| Keil 重编译 | ⏳ 仍用户侧（#1），编译前维持禁令 |

测试：**43 passed**（新增尾随字节走私拒绝 1 例）。**带动力上车前置条件不变：Keil 0 错误 + 继电器板照片 + B2/B5 台架全过。**

## F+** 第六轮复核修正（2026-09-08，评审指出 getter 链接回归，已修复）

- **P0 链接回归**：`retrofit_estop_latched()` 此前只在头文件声明、两份 .c 均无实现（补丁脚本 replace 锚点写错静默无操作）——已补实现并**写入后断言验证**；新增全量 C 符号自检：main.c 调用的 4 个 retrofit 符号全部有定义、头文件声明全部有实现、SW_Stop 4 个写点 3 个已门控+1 个是注释行。
- **来源白名单默认启用**：bridge 默认白名单 = 配置的 `pc_ip`（config.yaml 可用 `allowed_sources` 覆盖），非白名单来源的 UDP 一律丢弃。
- 仍未闭环（不变）：Keil 重编译（用户侧，编译前禁烧录）、继电器板照片、STATUS/RDK/IPM/田间闭环。

## F+*** Keil 重编译验证通过（2026-09-08）

- 用户在 Keil uVision(ARMCC 5.06u5)全量 Rebuild:**0 Error / 61 Warning(全部为原车遗留代码警告,retrofit.c/protocol.c/main.c 门控区零告警),Code=44616**,hex 已生成(OBJ/PWM.hex,本地)。
- 五轮评审的固件侧修复(P0-2/4/6/7、Fw-11、ESTOP 断能、上电提刀、getter)全部转为"已验证"。
- **带动力上车前置条件更新:①✅ 编译 ②⏳ 继电器板照片 ③⏳ B2 对拍(含 NAV=进 AUTO/HEARTBEAT=退 MANUAL/SW_Stop 断能实测)④⏳ B5 安全五项。**

### F+**** Keil 重编译验证通过（2026-09-14，命令行 headless，qoder 自跑）

- 机器上有 `D:\ruanjian\keil\KEIL32\UV4\UV4.exe`，用 `UV4 -r <PWM.uvprojx> -j0 -o build_log.txt` 全量重编，**不必再等用户手点 Rebuild**。
- 结果：**0 Error / 61 Warning（与 09-08 基线同数，未新增）/ Code=44840（09-08 为 44616，+224B）/ RO=1152 RW=1076 ZI=3068**，hex 已再生（`OBJ/PWM.hex`）。
- 交叉验证：`OBJ/PWM.map` 内 `retrofit_sbus_ok 0x08008863 Thumb Code 28 retrofit.o(.text)` 为**真定义**；`main.c` 的 `retrofit_sbus_ok declared implicitly` 警告消失 ⇒ 原型可见。
- 上一轮 `L6218E: Undefined symbol retrofit_sbus_ok` 根因：**中文路径 `大车proj/大车` 在 `git checkout/rebase` 时静默不生效**（命令报成功但文件没同步），已用文件系统 `cp` 修正（`f0ecf73`）。**教训：涉及中文路径的 git 同步，必须 `git diff` 到文件级核实，不能信命令返回码。**
- **带动力上车前置条件现状:①✅ 编译 ②⏳ 继电器板照片 ③⏳ B2 对拍(含 SBUS 失联两子情形) ④⏳ B5 安全五项 ⇒ 两条硬禁令仍未解除。**

---

## H. 外部整体审查（2026-09-09，codex·Astra）待办台账

> 报告全文：`docs/reviews/2026-09-09-project-review.md`（审查基线 94e1a99）。2026-09-11 逐条复验：**12 条中仅"STATUS 接收闭环"已被 D7 关掉，其余仍开**。前次复核中"tjcstr 已消失"的结论**有误**（main.c 为 GBK 编码，grep 按二进制跳过），Astra 原始判断正确，特此更正。

### H1. 🔴 数据资产安全（秋采 10 月中开拍前必修）
| # | 项 | 现状 | 证据 |
| --- | --- | --- | --- |
| H1.1 | ~~`split_dataset.py` 先清空后读源、路径指向只读仓~~ | ✅ 09-11 重写 | 路径改工作区、`_guard` 拒绝 JetBrains/工作区外、**先校验源再清空**、默认拒绝破坏性操作（需显式 `--force`）、`--dry-run`；测试 `tests/test_data_tools.py` 5 例 |
| H1.2 | ~~标注规范 `peony` vs `json2mask.py` 只认 `shaoyao`（会静默丢前景）~~ | ✅ 09-11 重写 | 冻结标签字典（`peony/shaoyao/芍药/shao_yao` 均认，background 同义），未知标签**报错**，全背景输出告警；测试 4 例 |
| H1.3 | 6:2:2 单图随机划分有邻帧跨集合泄漏风险 | 🟡 **机制已编码，泄漏未证伪** | 分组划分 + `split_manifest.json` 已实现（qoder `9e5774c`，按文件名首段分组）。**09-21 E1② 改掉两处**：恰 3 组时旧算式会让 test 集为 0，现在硬性三集合各≥1 组；组数 <3 从"告警并退回逐图"改成**直接拒绝**（正式评价不许静默降级）。同日补分组形态诊断与命名陷阱提示；**但分组清单要等 C1 秋采数据落地才能冻结**——"有分组功能"≠"邻帧不跨集合"，见 `docs/秋季图像采集清单.md` |

### H2. 🔴 控制权限与安全（上台架前必修）
| # | 项 | 现状 | 证据/方案 |
| --- | --- | --- | --- |
| H2.1 | MANUAL 失视觉未经请求切入 MCU AUTO | ✅ 已修（09-14；固件三项**已重编译 0 错误**，见下『H2 批次修复』表；剩烧录+台架复验） | `state_machine.py:43` vision_loss 对 MANUAL 无守卫；`main.py` LIFT 分支发 NAV(0,0)，固件 NAV⇒AUTO。需状态转换契约（适用模式×PC 状态×线上命令×MCU 模式） |
| H2.2 | AUTO 清零转角后仍叠加 `Switch_direction` | ✅ 已修（09-14；固件三项**已重编译 0 错误**，见下『H2 批次修复』表；剩烧录+台架复验） | `main.c:519` 清 angle 后 `send_angle` 仍 ±Switch_direction；需在执行处统一仲裁全部转向输入（4WS 解锁的前置） |
| H2.3 | MANUAL 缺 MCU 侧遥控失联停车 | ✅ 已修（09-14；固件三项**已重编译 0 错误**，见下『H2 批次修复』表；剩烧录+台架复验） | `retrofit.c` 仅 AUTO 查 `last_pc_ms`；`sbus_last_ms` 无读取方。断接收机/SBUS 线后旧指令仍被使用 |
| H2.4 | `tjcstr[30]` 缓冲区溢出 | ✅ 已修（09-14；固件三项**已重编译 0 错误**，见下『H2 批次修复』表；剩烧录+台架复验） | `main.c:266` 定义 30B；`:303/:331` sprintf 实际写 37B+ NUL=38B（GBK），越界 8B。改有界格式化 |
| H2.5 | ~~bridge 注入 ESTOP 覆盖 `last_pc_ms`~~ | ✅ 09-14 修复 | `bridge.py:49` 注入时仍 `last_pc_ms=now_ms` → 真实收帧时间被自身注入覆盖，连续注入无退出窗口。✅ 已拆分：`last_real`（仅真实帧刷新）与 `last_inject`（节流 500ms）；回归测试复现评审场景——70s 连续轮询下注入限频、60s 窗口过期即停止、真实时间戳不再被推进 |
| H2.6 | ~~bridge `poll_serial_frames` 丢弃 rest~~ | ✅ 09-11 已修 | `frame is None` 时先取 `rest` 再判断；半帧保留、噪声前缀只留末字节；新增 `tests/test_control.py` 跨边界 4 例 |
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

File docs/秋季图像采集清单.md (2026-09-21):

# 秋季田间图像采集清单（C1 任务执行文档）

> 目标：为秋季模型微调采集 200-300 张标注级图像 + 3 段验证视频。
> 依据：avi 帧域差异实测（夏季权重在当前田况过分割，fg≈0.55，双墙不可用）。
> **时限：2026-10-15 前**（之后杂草枯黄，域又变了）。
> 采集完成后图像放 `D:\ai work\zcode\autumn_data\raw\<类别>\`，命名见文末。

## 1. 设备与机位

- **必须用车上真机位拍，不要为了采集另装一个机位**：相机镜头离地 **100 cm**（台账 Hw-20，09-21 现场实测；旧稿写的"低机位 0.9 m" 是错的措辞，别照它改装机位）。俯角实测值待 M11b 补。**采集域=部署域**比清晰度、比构图都重要——机位一换，秋季素材与实车感知就不是同一个分布，模型与阈值全得重来。
- 没条件上车时用手机 substitute：手持模拟同机位（离地 ~0.9m、前倾 ~20°、镜头高度对准行间延伸方向），标注时注明。
- 分辨率 ≥1920×1080（与标定/训练域一致）；格式 JPG；视频 1080p25。

## 2. 拍摄矩阵（每格代表一个拍摄批次）

四个维度全覆盖，**每格 ≥15 张**，合计 240 张左右：

| 维度 | 取值 |
| --- | --- |
| 光照 | ① 晴天顺光 ② 晴天逆光 ③ 阴天（3 选 3 都要） |
| 时段 | 上午（侧影长）/ 正午 / 下午（逆光多） |
| 行况 | ① 行间干净（草少）② 行间中度杂草（主要工况）③ 行间茂密（接近封垄） |

**行况（杂草密度）三级量化标准**（拍前先读，每张照片按此打标签，回来才能分层回归）：

| 级别 | 定义（取其一即可，标注时注明用的是哪个口径） | 目测速判 |
| --- | --- | --- |
| 疏 clean | 行间地面裸土覆盖率 ≥70%；或 1 m² 行带内杂草株数 ≤5 株 | 土比草多，一眼见底 |
| 中 mid | 裸土覆盖率 30-70%；或 1 m² 内 5-20 株 | 草土相间，行墙仍清晰可辨 |
| 密 dense | 裸土覆盖率 ≤30%；或 1 m² 内 >20 株 | 草连成片，行墙需辨认 |

> 口径说明：**优先用裸土覆盖率**（拍照后拉网格数即可复核）；株数口径作为辅助。边界样本（恰在 70% 上下）归入较密一级。若同一段行带内疏密混杂，按 lookahead 区域（画面中下部 1/3）的主导状况定级。
| 视角 | ① 正对行间 ② 左偏 ~15° ③ 右偏 ~15°（模拟车体横向纠偏时的视野） |

优先级（时间不够先保这些）：
1. **晴天+中度杂草+正对**（主工况，≥60 张）
2. 晴天逆光+中度（逆光是分割翻车重灾区，≥30 张）
3. 阴天+中度（≥30 张）
4. 干净/茂密行况各 ≥15 张
5. 左右偏角随拍随带，不单独跑一趟

## 3. 内容要求（标注级）

- 画面内**必须含两条完整的芍药行墙**（左右边界都在画面里）——双墙中心线是监督信号。
- 帧与帧之间**位移 ≥0.5m**（避免大量近重复帧）。
- 芍药各生长阶段都拍：秋季叶片完整期/半枯期/枯萎期（若有）。
- 拍几张**干扰特写**（各 5 张即可）：滴灌带（蓝/黑管）、地膜残留、大块阴影、人脚/鞋入镜——这些是误检源，标注时重点照顾。

## 4. 视频验证集（3 段，不用标注）

- 沿行间匀速走拍 3 段：晴天逆光 1 段、阴天 1 段、任意 1 段；每段 ≥30s、1080p25、走直线。
- 用途：微调后的留出验证（回放测 status=dual 比例），**不进训练集**。
- 命名：`autumn_video1_sun_backlight.avi` 等。

## 5. 标注规范（回来后我出工具，你只管拍）

- 工具：labelme 多边形，两类：`peony`（芍药植株，含茎叶）/ `background`（其余一切，含杂草——行间除草只认行墙，杂草归背景）。
- 边界精度：叶片边缘贴 合到 ±3 px 即可，不抠细节。
- 遮挡/截断：出画植株按可见部分标，不预测。
- 标注量：从 240 张里标 **150 张**（矩阵每格按比例抽），我抽检 20 张质检。
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

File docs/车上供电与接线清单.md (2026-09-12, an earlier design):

# 车上供电与接线清单（方案 B，2026-09-12 定稿 v4 · 采购详版）

> 采购与接线照此执行。网桥不架高。
> **权威依据（RDK X5 设备手册原文）**：
> "开发板提供一路 USB Type C 接口(接口 1)，作为供电接口，需要使用支持 5V/5A 的电源适配器为开发板供电。
> 将电源适配器接入开发板后，绿色电源指示灯亮起，说明供电正常；3.1.0 版本后，橙色状态指示灯闪烁，说明系统运行正常。"
> 台账：`docs/参数差异台账.md` Hw-15/Hw-16。历史勘误见文末。

---

## 0. 一句话总览

```
48V 车电池 ─┬─[2A保险丝+TVS+磁环]─→ 48→5V/≥5A 模块 ─→ X5 供电口(USB-C 接口1)
            └─[2A保险丝+TVS+磁环]─→ 48→12V/≥1.5A 模块 ─→ 车端网桥 DC 口
X5 网口 ──普通网线──→ 车端网桥 LAN 口        全车共地
```

**买东西时唯一不能错的三条**：
1. **X5 是 5V，不是 12V**——买 48V→**5V** 模块，且电流标称 **≥5A（建议 6A）**。
2. **别买"只到 5V/3A"的模块**——15W 喂不饱 25W 的 X5，满载会重启。这是最常见的坑。
3. **网桥电压按它自带的适配器标签买**（9–13V 常见 12V），插头尺寸/极性先对上再下单。

---

## 1. 采购清单（逐项：参数 / 关键词 / 坑）
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

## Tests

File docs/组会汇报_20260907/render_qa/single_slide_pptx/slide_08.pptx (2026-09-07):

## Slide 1

研究背景

IPM 投影误差已分解，对策覆盖主要误差源

总体方案

理论方法

试验设计

进度与计划

安装高度

0.9m 机位下约 1.1cm，一次标定消除

俯仰角

误差随距离二次增长——远场只用于导航

畸变/垄形

先校正再投影；起伏交由 Kalman 滤波

标记点重投影误差 ≤2cm，工具链已备好

验收线

纯视觉芍药行间除草机器人 · 组会进展汇报 · 2026-09-07

8

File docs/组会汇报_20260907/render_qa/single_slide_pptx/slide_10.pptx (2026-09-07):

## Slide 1

研究背景

三组对比试验覆盖方法、机构与工程三层

总体方案

理论方法

试验设计

进度与计划

三组对比试验

1. 方法层：主动对行 vs 固定刀（各 5 趟）
2. 机构层：鸭掌铲 vs 弹齿（各 3 趟）
3. 工程层：时延补偿开 vs 关（RMS 偏差）

统一工况与统计

1. 0.5km/h、耕深 3cm、20m 试验段
2. 样方前后拍照，数据全部入 CSV
3. 均值±标准差 + 单因素方差分析
4. 结论边界：坡度≤15° 壤土芍药田

纯视觉芍药行间除草机器人 · 组会进展汇报 · 2026-09-07

10

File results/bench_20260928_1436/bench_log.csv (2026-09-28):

t_rel | iso | kind | seq | mode | speed | current_a | batt_v | limits | note | peer
0.008 | 2026-09-28 14:36:05.908 | first | 7 | 0 | 0.000 | 0.00 | 48.00 | 6 |  | 192.168.127.10
0.058 | 2026-09-28 14:36:05.958 | frame | 8 | 0 | 0.000 | 0.00 | 48.00 | 6 |  | 192.168.127.10
0.107 | 2026-09-28 14:36:06.007 | frame | 9 | 0 | 0.000 | 0.00 | 48.00 | 6 |  | 192.168.127.10
0.156 | 2026-09-28 14:36:06.056 | frame | 10 | 0 | 0.000 | 0.00 | 48.00 | 6 |  | 192.168.127.10
0.207 | 2026-09-28 14:36:06.107 | frame | 11 | 0 | 0.000 | 0.00 | 48.00 | 6 |  | 192.168.127.10
0.254 | 2026-09-28 14:36:06.154 | frame | 12 | 0 | 0.000 | 0.00 | 48.00 | 6 |  | 192.168.127.10
0.307 | 2026-09-28 14:36:06.207 | frame | 13 | 0 | 0.000 | 0.00 | 48.00 | 6 |  | 192.168.127.10
0.356 | 2026-09-28 14:36:06.256 | frame | 14 | 0 | 0.000 | 0.00 | 48.00 | 6 |  | 192.168.127.10
0.407 | 2026-09-28 14:36:06.307 | frame | 15 | 0 | 0.000 | 0.00 | 48.00 | 6 |  | 192.168.127.10
0.459 | 2026-09-28 14:36:06.359 | frame | 16 | 0 | 0.000 | 0.00 | 48.00 | 6 |  | 192.168.127.10
0.506 | 2026-09-28 14:36:06.406 | frame | 17 | 0 | 0.000 | 0.00 | 48.00 | 6 |  | 192.168.127.10
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

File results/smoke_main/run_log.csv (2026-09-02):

t | frame_id | state | status | lat_m | lat_comp_m | vL | vR | tool_mm | conf | latency_ms
0.026 | 0 | MANUAL | none |  |  | 0.000 | 0.000 | 0.0 | 0.000 | 847.9
0.893 | 1 | MANUAL | none |  |  | 0.000 | 0.000 | 0.0 | 0.000 | 102.8
1.012 | 2 | MANUAL | none |  |  | 0.000 | 0.000 | 0.0 | 0.000 | 93.8

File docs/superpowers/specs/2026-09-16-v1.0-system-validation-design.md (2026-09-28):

# 纯视觉芍药行间除草机器人 · 硕士论文实施方案 v1.0（整机系统验证主线）

> 本文件取代 v0.9 成为**现行方案**；`2026-09-08-v0.9-defense-first-design.md` 保留为历史记录，不再更新。
> 北极星：**答辩 2027-05、送审 2027-04 中旬**。制定日 2026-09-16。
> 事实权威序不变：设备手册 / 用户实测 / 现场确认 > 文档；文档与事实冲突时改文档。

## 0. 一句话总纲

以**整机设计与田间系统验证**为主贡献（导师口径已确认可接受），把对行误差沿
`感知行线 → 底盘横向偏差 → 刀具横向位置 → 除草与伤苗效果` 逐级拆开，每一环配一个**独立于被评价算法的真值**；
不再为凑新颖性制造方法创新点，也不保留撑不住的理论公式。

## 1. v0.9 → v1.0 变更（作者 09-15/09-16 确认，非我推测）

| # | 事项 | v0.9 | v1.0 | 依据 |
|---|---|---|---|---|
| Δ1 | 主贡献 | 创新点1＝"中间刀视觉主动对行方法"（方法贡献） | **整机设计与系统验证**；主动对刀降为系统功能 + 一项对照 | 作者选 C；导师认可"整机+田间就够" |
| Δ2 | 立论骨架 | 方法创新叙事 | **甲做骨（误差链验证）＋丙做壳（设计-研制-试验）** | 作者确认 |
| Δ3 | 田间单点风险 | 秋季只做"非头条试跑"，班车 2027-02~03 独扛 | **秋季升格为有完整记录的预实验**，与春季构成双窗口 | 作者确认"双保险" |
| Δ4 | 秋季范围 | 未钉死 | **只测自主沿行 + 偏差/失效记录；刀抬起空跑**；刀控、除草率、伤苗率一律推春季 | 作者确认（5 周窗口内并行度上限） |
| Δ5 | 理论块 | 保留 IPM 误差放大式作理论支撑 | **删除**（T4）；时延补偿降为工程处理与局限讨论（T6） | codex T4/T6 成立，我复核同意 |
| Δ6 | 转向 | 前轮 Ackermann 不作创新点 | 不变，但**必须把"硬件能力／拟用模式／已运行模式"三者分开写**（T2） | codex T2 成立 |
| Δ7 | 交付口径 | 未绑定 Word | **章节源码—参数—Word—校验记录绑成版本清单**（T1） | v14.docx 落后正文，已核实 |

## 2. 研究命题与四个子验证主张

**主命题（可检验，允许证伪）**：在芍药大田窄行间工况下，纯视觉样机能否在**不依赖 RTK 与激光雷达**的条件下沿行自主行驶并达到农艺可接受的作业指标；并按 `感知行线 → 底盘横向偏差 → 刀具横向位置 → 除草与伤苗效果` **分层验证与瓶颈定位**。
（09-21 复审 R6：在坐标、符号与时间基准统一之前，**不称"误差分解"**，也不把四组独立实验的 RMSE 相加当总误差预算。）

| 主张 | 测什么 | 真值来源（必须独立） | 口径（送审前不得改） | 现在缺什么 |
|---|---|---|---|---|
| **V1 感知** | 行中心线横向误差分布、失败率、最长连续失效；按光照（顺/逆/阴）与遮挡分层 | 人工独立标注的目标线（标注者不看算法输出） | 报 均值／标准差／95 分位／最大值 四量分列，**不混用**；失败帧计入分母 | 秋采 + 标注工时 |
| **V2 底盘** | 20 m 行段横向偏差、自主完成率、人工干预次数 | 地面拉线 + 钢尺（或外部标记点） | 有效行段判定标准在**下田前**写死；禁止只保留算法报 `dual` 的成功帧 | 外部基准测量方法未成文；B1/B2/B5 未过 |
| **V3 执行** | 刀位指令 vs 刀位**实测**、阶跃跟踪、重复定位、限幅、动作时间 | 百分表／外部刻度；**禁止用命令值冒充实际位置** | 厘米级；须含"挂草/撞石时能否抬刀"的动作时间实测 | 滑台未接线（Hw-12）、无刀位反馈、刀控未解锁（P0-7） |
| **V4 效果** | 除草率、伤苗率、对行偏差 | 样方逐株计数，作业前后固定时点 | 除草率按**株数**口径；伤苗判定标准与分母先定；是否复查再生要写 | 春季才能测；鸭掌铲幅宽未登记（对比不对等） |

**预注册的允许结论**（防"看完结果再定成功标准"）：允许得出"某一环是瓶颈""主动刀仅降低轨迹误差而未改善除草率/伤苗率""仅部分工况有效"。出现第三种情况时按分层表述，不重定义指标。

## 3. 章节外壳与每章要回答的问题

| 章 | 回答的问题 | 优先交付证据 | 现状 |
|---|---|---|---|
| 1 | 芍药行间哪个具体问题未解决，本文验证什么 | 直接相关研究比较表（研究对象—感知目标—是否主动横移—验证方式—局限）；农艺约束来源 | 文献仅 26 条且 23 条是感知/导航类，机具侧只有 3 条 → 需补 2023-2025 三条 |
| 2 | 结构与执行器为什么适配该问题（**按丙写：设计记录，不硬凑理论**） | 实车尺寸与照片（Hw-14/Hw-19）、机构行程/刀宽/离地与深度、既有平台与本人改造区分 | 表 2-3 八类机构选型已有推导；尺寸与刀宽缺登记 |
| 3 | 视觉能否稳定给出作业目标 | V1 + 失败帧 + 光照/遮挡分层；**三个"目标线"概念分开定义** | 只有 V1 的第一层有数 |
| 4 | 目标怎么变成底盘与刀具运动，误差怎么变 | 统一坐标图、实际控制律、V3、故障响应记录 | T5 误差定义未闭合；T2b 几何式有误 |
| 5 | 主动对刀相对固定刀带来什么可重复效果 | 三层验证的 L3：固定条件对照、独立行段、原始计数、区间与失败样本 | 无数据（正确：初稿已声明不含田间数据） |
| 6 | 每条结论由哪组结果支持、在哪失效 | 按研究问题总结效果量与适用工况 | 仍把未完成模块列成结论（P8/P9） |

## 4. 三层证据链与秋季预实验的确切产出

- **L1 离线**（M 轨）：C1 秋采 → 分组划分与 `split_manifest.json` 冻结 → 独立标注 → V1。
- **L2 台架/受控**：B2 对拍 + H2 组合场景 ①–⑧ + 故障注入 + V3。（09-21 起关闭判据为 ①–⑧：⑧＝F3 夺权场景；⑦＝原"已知遗留 send_angle"项，不是新增）
- **L3 田间**：秋季预实验（10 月中前）＋ 春季正式对照。

### 4.1 两道准入门（09-21 修订：原来三处排期互相打脸）

| 门 | 准许做什么 | 必须过的项 | 目标日 | 负责人 |
|---|---|---|---|---|
| **门 N｜导航验证准入**（**在样机＝真实车 2.15 m 上**） | 田间**自主沿行空跑**（刀具锁定提刀、禁止横移） | B1 烧录 → B2 对拍（含 SBUS 失联两子情形）→ **导航专用安全三项**：模式切换可观测、链路失联停车、刀具物理锁定确认 | 10-05 | 用户执行，qoder 出验收脚本 |
| **门 F｜完整作业系统准入**（同样在真实车上） | 落刀作业、除草率与伤苗率采集、主动对刀对照 | **B5 安全动作实测全项** + 刀控 P0-7 解锁 + 滑台接线 + V3 台架记录 | 2027-01 底 | 用户 + qoder |

**跨车迁移边界（09-21 定样机＝真实车 2.15 m；同日复审后收窄措辞）**：能跨车的是**软件模块与上代车上的调试记录**——协议与帧格式、固件模式机代码、失联保护与状态新鲜度实现、控制律结构、分割模型本身。**搬到样机后仍须逐台再确认**：接线与执行方向、SBUS 失联在这台车上是否真停车、急停实际切断哪些电源、供电、现场链路、实测时延数值（数字不跨车继承）。一句话：**协议解析测试通过 ≠ 这台车确实停下来了**，两层证据不得互相顶替。<br>**凡横向指标一律不可跨车引用** —— 轮距 191 vs 301 cm、轮迹与作物行的相对位置不同、有效双墙占比不同。（09-21 撤回：此处旧文写"跨 5.5 vs 8.6 个行距"并据此称压苗，行数算术推不出压苗，见本节"前置未决"条与 `tools/geometry_check.py`。）<br>相机内参/IPM 属**待核验**而非必然不同：车更宽不是光学参数变化的充分原因，能否复用取决于相机、镜头、成像设置、安装姿态与坐标定义是否一致。当前两车这些档案都不全，所以**按"样机重新标定"执行是合理的工程选择，但要写成核验要求**。`results/smoke_ipm/ipm_params.json` 那类在上代车/旧机位（其实是全黑合成图）产出的参数，**不得直接用于样机**。故第 4/5 章每个横向数据都必须标注采集自哪台车。

**门 N ≠ 门 F。** 秋季只申请门 N；B5 全项与"解除两条硬禁令"属于门 F，**不再写在秋季那一行里**。两条硬禁令（禁止实车 AUTO、禁止带动力接线）在门 N 通过前同样有效——门 N 本身就是要按证据把它们逐条松开到"仅空跑沿行"这一档。

**秋季预实验（10 月中前，约 4 周）——写死范围，不留模糊目标**

- 必做：**导航验证模式**下 AUTO 自主沿行；V2 全指标 + 失效记录（自主完成率、人工干预、失视觉段、超限、未完成行段）。
- **导航验证模式必须先定义再实现**（09-21 复审 R1：现有代码做不到"抬刀空跑"）：
  `retrofit.c:244` 约定 `lift_bits` 位 **1=提刀**，而 `pc/main.py:211` 在 AUTO 每帧发 `pack_tool(tool_mm, 0)` → **AUTO 现在是在请求三梁落刀**。
  因此该模式的约束是显式三条：① `lift` 恒为 `0x07`（三梁全提）；② **横移在输出层被锁死**；③ 切模式与视觉恢复时约束保持。
  ⚠️ **09-21 复审订正第②条的写法**：原文"横移指令锁 0"不成立——`retrofit.c:271` 是 `err_mm = tool_offset_mm - applied_mm`，假定当前位置估计 20 mm 时目标 0 会得到 -20 mm 误差并**产生回中脉冲**。**"移动到零位"与"禁止该轴运动"是两回事。**空跑约束必须落在**实际输出层**（该轴不再产生脉冲／使能被撤），并且要覆盖五种边界：进入空跑模式、退出空跑模式、链路掉线、旧命令残留（换主前已排队的目标）、急停复位后。
  同理，**刀具物理锁定的确认不能由目标数值代替**——那是机械状态，要靠现场核对表（S3）。
  **不接受三种偷懒实现**：把初始 lift 改成 0x07（后续帧会覆盖）；把 `tool_offset_mm` 置 0（会回中，见上）；或"干脆不发 TOOL"靠 `retrofit.c:257` 的看门狗默认提刀——那是兜底态，不是实验约束。验收要**抓线上帧**核对 lift 字段与固件输出状态，并**实测该轴在手推下不动**，不看代码意图。
- 顺带（同一次下田办三件事）：C1 图像采集、**样机机位外参（IPM）标定**（不叫"低机位"，相机离地 100 cm，见 Hw-20）、光照矩阵。
- **明确不做**：刀控接入、主动对刀、除草率与伤苗率 —— 全部推春季。
- 采前必须成文的三件：① 有效行段判定标准（决定分母）；② ±5 cm 到底是最大绝对误差还是 95 分位；③ 每趟的干预与失效记录表字段。
- **前置未决（09-21 复审后问题已换）**：车宽那一半已经关掉——`ch02:14` 的 ≤60 cm 被 Hw-20 现场实测否掉（样机 2.15 m），所以"60 cm 放不下 3 把刀"这个两难本身不成立，不用再量。**剩下的是田里那张横断面**：轮迹相对行线的横向偏差（M15）、胎宽（M14）、作物保护带、行驶跟踪误差。这四项决定 V4 伤苗率分母与"一次清几条带"的口径。**⚠️ 复审撤回了本节旧推论**：轮距 191 cm ÷ 行距 35 cm = 5.46 个行距，说的是"两轮之间跨过几行"，推不出"轮胎压住作物行"；行距 38.2 cm 时 191 cm 恰为 5 个行距，两轮正落在行间。`tools/geometry_check.py` 已改为只报事实、不下压苗结论（含该反例的测试）。见 `docs/整车尺寸实测表_20260921.md`。
- 它承担三个作用：把"首次整机下田"从班车窗口挪走；给第 3 章真实秋季域分母；给第 5 章一个季节×工况可行性证据。

## 4.2 秋季执行序列（09-21 定：控制栈尚未装车，真实车在地里、不好运）

**约束的本质**：搬运是**一次性事件**——真实车在地里，不能反复拆装试错。所以凡"可在上代车上完成的"必须**全部做完再搬**，搬过去只做"只能在样机上做"的事。

| 步 | 在哪台车 | 做什么 | 出门判据 | 时间 |
|---|---|---|---|---|
| **S0 物候预检（不搬车，半小时）** | 人带相机去田里 | 拍 50 张当季照片，**留两份独立结果**：<br>① **人看原图**——逐张记"作物墙看得见吗／可通行带看得见吗"（人工判断，不看模型）；<br>② **算法跑**——用现有权重跑 `tools/pre_annotate.py` 记前景占比与多边形完整性；<br>③ 两者不一致时**必须写下原因**，不许只取一个数。短视频补查连续失效（50 张静图的总占比替代不了） | **两栏同时通过**才押 V2。**前景≈0 不能直接判"没作物"**——也可能是域差、机位、曝光或模型漏检；反之占比正常也不证明左右墙位置、目标线误差与连续可用性合格。**人工判看不见 或 算法连续失效 → 触发 §8 退路**，秋季改验证"垄沟/裸土通道提线"可行性，C1 图像照采 | 本周任意一天 |
| **S1 装车与链路** | 上代 3.25 m | 装控制栈（大板+X5+相机+网桥）→ B1 烧录 → B2 对拍（含 SBUS 失联两子情形）→ 电脑能否控住、失联能否停车 | 上代车"能被电脑控制"且有帧记录；**这一层的软件模块与调试记录可复用，但搬到样机须按 §4.1 逐台再确认**（接线、执行方向、失联是否真停、急停切断范围、供电、实测时延） | 09-21 → 09-28 |
| **S2 空跑冒烟** | 上代车，平地/无作物 | 人工拉平行标记带当地面基准，跑一次 感知→控制 闭环；只看"能不能沿走、失联停不停"，**不要求精度指标** | 无失控、无越界、干预次数可数 | 09-28 → 10-04 |
| **S3 搬运日** | → 真实车 2.15 m | **先断电**：接线核对表逐项勾（48V 极性、共地、保险丝、刀梁锁定状态、急停切断范围）→ 万用表量过再通电 | 核对表全绿才允许带动力；**两条硬禁令在 S3 之前不得解除** | 10-05 前后 |
| **S4 样机现场项** | 真实车 + 目标田块 | ①样机机位 IPM 标定（地面标记点，**上代车的 `ipm_params.json` 不得沿用**）②C1 秋采图像 ③门 N 预实验：刀锁定提刀、自主沿行、记 V2 与失效 | 采前协议成文；每趟先判"算不算有效行段" | 10-05 → 10-15 |

**搬运日必须带的**：备用 USB3.0 短线（相机线材已两次实测掉设备）、保险丝与端子、网线、便携电源、卷尺与地面标记签、断电可用的万用表。

**由此产生的两个诚实结论**：① v1.0 §1 的"双保险"里，秋季能保的是**图像与标定层**（C1 + 样机机位标定），**沿行自主（V2）是 S3/S4 成功才有**，若搬运日只剩一次机会而失败，V2 就落到春季——这句话要如实写进方案，不能到 4 月再解释。② 上代车上的任何**横向**数据（对行偏差、双墙有效性）都不得写进样机结果，见 §4.1 迁移边界。

## 4.3 权限与车辆档案骨架（2026-09-21 作者批准定稿）

**两根正交轴，禁止揉成一个枚举**（揉成 MANUAL/上代/真实/AUTO 会立刻出现"真实车用遥控算什么""AUTO 中换档案怎么办"这类无解组合）：

| 轴 | 取值 | 只管 |
|---|---|---|
| **控制权限** | `MANUAL`（遥控）/ `TELEOP`（PC 遥操作，人在环）/ `AUTO`（无人）/ `ESTOP` | 指令源、谁能夺权 |
| **车辆档案** | `PREV`（3.25 m）/ `REAL`（2.15 m） | 车宽、轮距、相机几何、刀布置、米↔像素换算 |

**档案轴永不影响权限判定，权限轴永不影响换算参数。**

### 档案：上电握手，运行中不热切

- PC 侧 `config/vehicle_profile.yaml` + 固件侧一份镜像；**上电时握手校验，不一致 → 拒绝进 AUTO 并在 STATUS 报警**。
- 理由：档案装的是换算量，行驶中切换会让控制量跳变；而换车当天本来就要重新上电接线，热切省下的时间≈0。
- **档案号必须进 STATUS 帧回传，并写进 `run_log.csv` 每一行。** §4.1 定了"横向指标禁止跨车引用"，日志里认不出车，那条规则就无法执行、论文也无法标注数据来源。
- ⚠️ 这不是纯软件改动：STATUS 帧加字段要**五处同步** —— `common/protocol.py`、`firmware/protocol.c`、`common/uart_vectors.py`、`pc/status_rx.py`、`tests/test_protocol.py`。漏一处就是 PC 与固件字段错位（那正是 `status_rx.alarm()` 要抓的事故）。

### 权限：夺权不得依赖任何链路

- **现场夺权走 SBUS 空闲通道**（**09-23 逐通道重扫全工程，订正本行旧数据**：活代码只用到 `ch[0]~ch[6]`——0 工作按钮、1 纵向↔横向、2 转弯方式、3 前进↔后退、4 油门摇杆、5 方向摇杆、6 停车/推拉杆互锁；`ch[7]`/`ch[8]` 的引用**全在注释里**（曾被规划为"缩回""低速"，说明发射机上大概率有对应实体开关）；`ch[9]~ch[15]` 只剩解析行。⇒ **空闲 = `ch[7]~ch[15]` 共 9 个**，夺权档优先 `ch[7]` 或 `ch[8]`。旧文"0~8 用满、9~15 空闲"错在把注释掉的引用算成占用、又把两个真空闲通道算成已用）。⚠️ **键位↔通道号映射仍未建立**，用发射机自己的通道监视页 5 分钟建表，并入 C4。拨到"现场"档 → 固件立即 `mode=MANUAL` 并**锁住 AUTO 请求**（此后 PC 发 NAV 也不进 AUTO），直到拨回。**这条判断写在固件里，不写在 PC 里。**
- **进 AUTO 五个必要条件，缺一不可**：① 档案握手一致 ② SBUS 新鲜（复用现有 `retrofit_sbus_ok()`）③ 遥控权限档在"允许无人"位 ④ 无 ESTOP 锁存 ⑤ PC 侧显式按键。
- 出 AUTO 三条路并存：HEARTBEAT 到来（`retrofit.c:70-73` 已实现）、遥控拨回现场档（新增）、ESTOP（已有）。

### 控制路径上的三个权限洞（必修，进门 N 准入）

证据状态列很要紧：下面是**静态控制路径分析**（读代码得出），没有一项做过硬件动作测试。把它们写成"已观察到的实车事故"同样是过度声明。

| # | 位置 | 问题 | 后果 | 证据状态 |
|---|---|---|---|---|
| **F1** | `retrofit.c:93→:102` | 收到 NAV 帧后 `mode = MODE_AUTO` **无现场许可、无档案校验、无链路条件**。<br>⚠️ 09-21 复审更正措辞：`:93` **已经有** `estop_latched` 检查，不是"五条件一条都不看"，缺的是 ①②③⑤ 四条 | PC 一按，车从"人在遥控"直接变无人，中间无现场确认 | 静态路径，未做实车动作测试 |
| **F2** | `retrofit.c:124-129` | `retrofit_clear_estop()` 把 `lift_bits = 0`（而 `:121` 约定 **1=提刀**），与上电默认态 `:361`（置 1 提刀）自相矛盾 | **潜在落刀路径**：若清锁时最后一条 TOOL 仍新鲜（<500 ms），会走落刀分支；TOOL 已过时则按 `:257` 走默认提刀。**不是"按一下物理复位一定瞬间落刀"** | 静态路径。**且全工程只找到 `clear_estop()` 的定义与声明，没找到按钮的实际调用点**——该函数当前是否被接线使用都待确认 |
| **F3**（09-21 复审新增） | `retrofit.c:105-113` `retrofit_on_tool_frame()`、`:251` `apply_outputs()`、`stepper_update` | **TOOL 帧只检查长度与急停锁存，不检查 MANUAL/AUTO**；横移执行同样只看急停不看模式 | 只给 NAV 加权限门**挡不住非当前指令源的 TOOL 动作**：现场夺权把 mode 改成 MANUAL 后，延迟到达的 TOOL 仍会影响升降 | 静态路径，未做硬件动作测试。**修权限契约时必须覆盖全部执行命令**：谁能控制升降/横移、换主时怎样处理旧目标、急停及复位后的输出默认态。验收场景须含"现场夺权后 PC 继续发 NAV 和 TOOL"的组合 |

### TELEOP：第四态，同时是延迟测量载体

链路 = 相机→X5→网桥→PC→网桥→X5→串口→MCU。安全条件：MCU 侧 PC 看门狗（500 ms 无指令停车，已有）+ 人工夺权通道仍然有效 + **因视野受限必须限速**。

**测延迟的口径必须先定，否则数字不作数**（"PC 发了包"≠"轮子转了"）：

- **一次性校准（推荐先做，不改固件）**：手机 60 fps 同框拍屏幕与车轮，逐帧数"按键→轮动"，误差 1/60 s≈17 ms。
- **长期测量（要改固件）**：PC 发指令带 seq+时间戳，MCU 在 STATUS 回传"最后执行的 NAV seq 与本地时刻"，两边用心跳粗共钟。

### 感知失效分级：一个布尔不够

`main.py` 现在只有 `usable = lat_px is not None`。"前面没芍药"至少三种含义，动作必须不同：

| 级 | 情况 | 动作 | 算故障？ |
|---|---|---|---|
| L0 | 双墙有效 | 正常 AUTO | 否 |
| L1 | 仅单侧墙有效 | **降速**继续 + 记一次降级事件 | 否，但要计数 |
| L2 | 无墙，且距行尾尚远 | **限坡度减速→停车→提刀→等人工**；禁止"沿最后一条线继续开" | **是** |
| L3 | 无墙且**有独立的边界依据**（纵向剩余距离或已知行尾坐标）才允许判正常终止 | 停车提刀，报"作业段结束" | **否，正常终止** |
| **L2.5**（09-21 复审：**当前唯一可实现的行尾处理**） | 无墙、且**没有**任何独立边界依据 | **停车 + 请求人工确认**，不声称自动区分行尾与感知失败 | 保守：两类都当需要人来判 |

L2/L3 分不清会出两种事故：把地头当故障→每行都要人跑去处理；把故障当地头→车停在田中你以为干完了。判据只能是**纵向剩余距离 + 持续时间 + 是否已知行尾**。

⚠️ **09-21 复审指出的实现边界**：L3 需要纵向剩余距离或已知边界，而**目前主入口没有这项可靠依据**。所以在拿到行尾坐标/剩余里程之前，**不得声称能自动识别正常作业终止**；采取 L2.5 的保守行为（停车并请人工确认）。这不是偷懒，是因为把"感知失败"误判成"干完了"的代价不对称。

⚠️ 现有 `morph_process.py:189` 的"单墙就 +200 像素粗偏移"**不能当 L1 实现**——它是占位不是推断。真正的 L1 需要"另一侧墙 + 标定行距"，而"标定行距"这个数目前不存在。

### 相机标定分层（回答"不标可以吗"）

- **内参不用重标**：`data/calib_params.npz` 的 fx 790.5/fy 795.8 + 畸变是相机自身属性，同一颗 imx291、同 1920×1080、同镜头就继续有效，不必重摆棋盘格。
- **外参（IPM 单应）随车变，但田里 20 分钟可标**：地上摆 4 个已知间距标记点解一次 H 即可。
  ⚠️ **09-21 更正我上一版写的那句"已有 reproj 先例，流程是通的"**：`results/smoke_ipm/ipm_params.json` **不是标定，是求解器的冒烟测试** —— 它的源图 `frame.jpg` 像素 **mean=0.0 / std=0.0（全黑）**，那些"点"不是人眼看着真实地面标的，所以 `reproj_mean_m 0.00588` 只证明"DLT 能把自己的合成输入解回去"，与相机、车、地面无涉。**结论：仓库现存零个真实外参标定。**
- **因此 E2⑤ 的定义改了**：不是"把现有文件接进 perception"（没有有效文件可接），而是 ①做一个**带来源校验的加载器**，让合成图/全黑图/超差/档案不匹配的标定文件**根本进不了生产链路**；②占位几何保留，但每次启动**显式标注为占位**，不让它的数字被当成实测；③真实外参先在**上代车 + 平地拉线**上做出来（比田里容易，不必等 S4），S4 再在样机上做一次属于 `REAL` 档案的标定。
- **上代车 S1/S2 阶段可以不标外参**（那阶段不报横向指标）；**S4 在真实车上测 V1/V2 前必须标**，否则"厘米级误差"没有米制基准。
- **硬前置 = E2⑤**：`perception.py` 现在不读 `ipm_params.json`，不修则标了也白标。

## 5. 论文—代码一致性修复清单（P 区，逐条到位置）

| # | 位置 | 问题 | 改成什么 | 依据 |
|---|---|---|---|---|
| P1 | `10_output/thesis_draft_v14.docx`（09-09 生成） | 仍含 0.7163@201、后轮反向偏转、NAV2 已实现、NEMA17 步进 | 重出 Word 并与章节源码绑版本清单 | 已核实四项全在 |
| P2 | `ch02:35`、表 2-2 行 44 | "主作业模式采用全 4WS" 与 ch04:16 前轮转向自相矛盾 | 改为前轮转向 + 后轮回正；硬件能力另句说明 | 我 09-14 漏改 |
| P3 | `ch04:30` | 前轮回转半径仍用后轮距 `B_r`，同页式 4.2 用 `B_f` | 前轮统一 `B_f`；补 R 符号约定 | codex T2b 成立部分 |
| P4 | `ch03:20 / :71 / :75` | 声称 IPM 参数热更新、边界时间滑动平均、草带质心+可配置行距回退 | 逐项对齐到实际函数；未实现者标"计划"或删除 | 代码里三样都没有 |
| P5 | `ch03:65` | `ΔY/Y≈ΔH/H+…` 矩阵比值未定义、单应具比例等价性 | **删该式**；若需理论，改做标定邻域数值敏感性 + 独立地面点检验 | codex T4 |
| P6 | `ch04:60` + `pc/control.py:27`、`pc/main.py:209` | 增量式 PID 表述错；图像偏差未减刀位实测 q | 画坐标/信号图：目标刀位（视觉）− 刀位实测 q；视觉外环/位置前馈/伺服内环分开 | codex T5 + deck 第 13 页 |
| P7 | `ch04:44` | 用前移量 `vτ` 做横向补偿，代码实为 `ėτ`；统计量口径也不对应 | 统一为 `e+ėτ`；四项时延分开测；降为工程处理与局限 | codex T6 |
| P8 | `ch04:40/:54/:60/:70` | "pytest 覆盖全部转换""四电机电流与过载保护""经仿真与台架整定""瓶颈在感知端" | 逐条改四态标注（已设计/已编码/已台架/已田间）；电流仍返回 0 不得写成已具备 | codex T7（原文带 `<待补充>`，但断言仍过度） |
| P9 | `ch03:83` 小结、`ch06:10` 结论 | 仍写"峰值 mIoU 0.7163" | **0.7163@201 本身不是错，错在当"峰值"报**。修法：先冻结"数据划分 + checkpoint 文件/哈希 + epoch + 该轮完整指标"，正文按**同一轮成组引用**（76 轮：mIoU 0.7459／前景 IoU 0.6342／背景 IoU 0.8576；201 轮：0.7163／0.5978／0.8347），可分别报"全程峰值"与"选用模型"，**禁止只换 mIoU 而保留别轮的背景 IoU 拼数**；并说明验证集峰值≠独立测试成绩 | **我 09-14 只改了 ch03:53 正文，漏了这两处**；成组引用要求来自 09-21 复审 R5 |
| P10 | `ch02:14`、`ch05:8` | 行距 30~60 cm、坡地 5~15° | 改 30~40 cm、0~15°（Hw-19 现场确认）；并连带重算通过性余量 | 台账 Hw-19 |
| P11 | `ch04:50` | "限深板摆角传感器"深度监测 —— 该硬件无任何登记 | 删除或改"当前无深度反馈"，与决策 D6 一致 | 台账；deck 第 15 页 |
| P12 | `ch02:80` | 电推杆 12V/行程 100mm | 改 48V/200mm/10mm/s/3000N | 台账 Hw-9 |
| P13 | `docs/决策依据说明.md:58` D8 | "实车无转向执行器、弃用阿克曼 4WS" 与 Hw-13、ch04 现状冲突 | 标"已作废（09-14 转向策略重定）"并留原结论 | 台账 Hw-13 |
| P14 | 文献 | 26 条中除 1 条 2026 外最新到 2018；41 处 `[[REF:]]` 占位 | 补赖汉荣 2023、Yang 2025、Ponnambalam 三条 + 比较表；逐条核占位符 | codex §四 |

纪律：P 区全部走 chucao_prj 的 `thesis_cau/` 例外授权，**手术式提交**（只 `git add thesis_cau/...`），每条独立 commit 并注明 P 编号；改完报 HEAD。

## 6. 工程修复批次（E 区）

- **E1（我写的两个 bug）→ ✅ 09-21 已编码并复审订正，待 zcode 审。**全量 `python -B -m pytest tests/ -q` = **120 passed**（09-14 收工 89；09-21 复审基线 117）
  ① `pc/status_rx.py`：MCU 重启后序号回退会被长时间拒绝 —— **09-21 更正我的措辞**：不是"永久拒绝"。按 `_seq_newer` 的 16 位回绕，重启前序号 ≥32769 时下一帧即恢复；最坏（重启前 ≈32768）约 **27 分钟**无 STATUS（codex 实测 seq1000 → 50.05 s 恢复，与此模型一致）。
  修法**不能**写成"连续 ≥50 帧被拒且 stale 即视为新会话"——同一旧帧重复 50 次也会满足它，那不是重启证据（09-21 复审指出）。改为：**连续 ≥50 帧被拒、且这些帧的序号严格互不相同且单调递增、且 `stale()` 成立** → 判定为重新同步，接受并重置基线；**重新同步只恢复状态显示，绝不自动恢复 AUTO、绝不清除急停锁存**。协议层面应另加显式会话/重启握手（`boot_id` 或序号 0 保留位），本轮先不改协议，故在文档里记为已知限制。
  回归测试至少覆盖：正常回绕、重启、重复帧、乱序、长时间静默后恢复、重新使能六种组合。
  ② `tools/split_dataset.py`：恰 3 组时 `round(3×0.6)=2 / round(3×0.2)=1` → **测试集为空**；且 <3 组静默退回逐文件随机。改为：分组模式保证三集合各≥1 组，不足则**报错拒绝**（正式实验模式不得静默失去独立测试前提）。**注意：现有"少于 3 组退回逐图"的回归测试要同步改成断言拒绝**，不得保留旧行为。
- **E2（codex 其余三项，不需实测即可定）** ③ `telecontrol.c`：把 `UART1_Rec_Len == SBUS_DATA_LEN(35)` 纳入有效性条件（`SBUS_DATA_LEN` 已确认为 35，条件可精确写；我 09-14 以"怕误杀"为由挂到 Hw-17 是判断失误）；④ `common/mjpeg.py`：`settimeout(None)` 改有界读 + 帧龄上限与超时告警；⑤ `pc/perception.py`：加载已存在的 `ipm_params.json`（H5.2）。
  **09-21 复审批次后的实际进度**：⑤ 做了一半——前置那件"没有有效文件可接"已经解决（`calib_ipm.solve()` 写来源字段、`pc/ipm_io.py` 建好并跑通"真实 solve() → 真实加载"闭环）；但 `perception.py` 仍用占位几何、`load_ipm_params` **至今没有调用方**，"加载器 → 感知入口 → 控制量纲"这一环**没接**，所以**不得称 IPM 链路已完成**。③ **已编码 + 已编译**（09-21 本批）：`telecontrol.c:142` 的有效帧判据从两条件变三条件（长度 35 ＋ 帧头 `0x0F` ＋ XOR）。理由与 H2.3 同源：短帧时 XOR 循环与 `rec_sbus_data[34]` 照读数组里**上一帧留下的旧尾巴**，旧尾巴本身有效，于是帧头与 XOR 可能同时通过、而 16 个通道字是两帧的混合。`UV4 -r` = **0 Error / 60 Warning**（基线 61，少的那条正是 `UART1_Rec_Len` "算了但没用"），Code=44848。**四态里这只到"已编译"，B2 ④(a)(b) 未做前不得称已台架。**
  ④ **已编码 + 已单测**（09-21 本批）：阻塞生成器 `iter_frames` 删除，换成 `StreamFeed`（读线程 + 非阻塞 `get(max_age_s)`）。复审点到的两件事都落了：①"有界 recv 但仍在生成器内部无限重试，主循环照样跑不动" —— 现在重连与 socket 超时都只发生在读线程里，实测把 connect 卡住 5 s，消费端 200 次轮询仍在 0.5 s 内全部返回；②"缓冲内取最新 JPEG 不等于采集端最新帧" —— 帧龄改称**本地收到该帧最后一字节的时刻**，代码与测试都写明它是玻璃到 PC 延迟的**下界**，不得当作端到端时延报（B8 四项口径继续分开）。`pc/main.py` 在无帧拍上给 `NO_FRAME_RESULT` 而不是拿旧图再推理一次，`VISION_LOSS_S` 与 GUI 按键因此在流断时仍可达。**未与真机 X5 联调**，属"已单测"而非"已台架"。
  ⚠️ 编号勘误：09-21 有一条 commit 把加载器标成 E2③，按本节的编号实际是 **E2⑤**（③ 是 SBUS 长度条件）。缺口清单与本节同批改正。
- **E3（动控制权限语义，须单独批准；09-21 骨架已批准，实施仍等 zcode merge）** → 展开为 §4.3 的六件事：
  ① **F1** 修 `retrofit.c:102` 无条件进 AUTO，改为五必要条件全满足；② **F2** 修 `retrofit_clear_estop()` 的 `lift_bits=0`（复位潜在落刀），与上电默认态一致改为提刀；**②′ 09-21 复审新增 F3：TOOL 帧与横移执行都不检查模式**（`retrofit.c:105` 只查长度与急停），权限门必须覆盖**全部执行命令**而不是只给 NAV 加门，并定义换主时旧目标怎么处理、急停及复位后的输出默认态；
  ③ 车辆档案 `PREV/REAL` + 上电握手 + **档案号进 STATUS 与 `run_log.csv`**；④ SBUS `ch[9]` 现场夺权档，判断在固件内，夺权后锁住 AUTO 请求；
  ⑤ `MODE_TELEOP` 第四态（限速 + 复用 PC 看门狗 + 夺权仍有效）；⑥ 感知失效 L0–L3 分级，L2 停车提刀；**L3 需要纵向剩余距离或已知行尾才允许判"正常终止"，当前主入口没有这项依据，故先按 L2.5 实现为"停车 + 请求人工确认"，不声称自动识别作业结束**（09-21 复审）。
  ⚠️ ③ 会改 STATUS 帧格式 → **五处同步**（`protocol.py` / `protocol.c` / `uart_vectors.py` / `status_rx.py` / `test_protocol.py`），并需重跑 `UV4 -r` 核对 build_log 与 map。
- **E4（用户侧硬件门）→ 09-21 复审：不能画成一条串行链，两门的入口不同**
  · **门 N 链（秋季，只申请空跑）**：B1 烧录（编译门槛已过，hex 现成）→ B2 对拍含 SBUS 失联两子情形 → **导航专用安全三项**（模式切换可观测、链路失联停车、刀具物理锁定确认）→ 台架证据申请门 N。**不含 B5。**
  · **门 F 链（春季前）**：继电器板端子照片定刀控（P0-7/H5.4）→ 滑台接线 → V3 台架 → **B5 安全动作实测全项**。
  ⚠️ 09-21 撤回旧写法的两处错位：① 原 E4 把"继电器照片定刀控"排在 B5 **之后**，而 B5 的原始清单（缺口清单 §B5）依赖提刀与滑台实测，次序反了；② 单链画法让人以为秋季要过 B5。**S1/S2 在上代车上带动力验证的是"调试平台准入"，"样机准入"是另一件事**——两条禁令（禁止实车 AUTO、禁止带动力接线）针对样机，S3 前不得解除。

## 7. 时间线倒排

| 时间 | 轨 | 里程碑 | 门槛 |
|---|---|---|---|
| 09-21 → 10-05 | A | **门 N 准入**：S0 物候预检 → 门 N 链（B1 烧录 → B2 对拍含 SBUS 失联两子情形 → 导航专用安全三项）→ 导航验证模式实现并**抓帧 + 手推该轴不动**双验收 | 刀具物理锁定确认 + 失联停车实测 + 空跑输出层锁横移。
**注**：B5 全项**不在此行**，属门 F（2027-01 底） |
| 10-05 → 10-15 | A+M | **秋季窗口**：门 N 下的自主沿行空跑预实验 + C1 秋采 + **样机机位外参标定**（相机离地 100 cm，"低机位"是 ch02:23 的错措辞，见 Hw-20）+ 光照矩阵 | 采前测量协议成文；预实验数据入库 |
| 10 月中 → 11 月底 | M | 标注、V1 分层评价、IPM 重标定、E1/E2 修复 | 分组清单冻结 |
| 11 月 → 12 月 | A | H2 组合场景 ①–⑧ + 故障注入 + V3 台架项（门 F 前置） | 台架记录入缺口清单，逐条从"已编码"升"已台架" |
| 12 月 → 2027-02 | 写作 | 第 2 章（丙外壳）+ 第 3/4 章（甲：坐标与误差链）+ P 区全清 | 新 Word 版本清单 |
| 2027-01 底 | A | **门 F 准入**：B5 安全动作实测全项 + 刀控接入 + 滑台接线 | 系统"可下田作业"冻结；两条硬禁令此时才谈解除 |
| 2027-02~03 | 田间 | **春季正式对照**（主动刀 vs 固定刀、除草率、伤苗率） | 田块书面确认（至今未拿到） |
| 2027-04 初 | 写作 | 第 5 章结果 + 全文合成 | 送审 |

## 8. 前提验证门与降级（C 路线下重写）

| 假设 | 状态 | 验证动作 | 失败退路 |
|---|---|---|---|
| 春季田块可下田、有可见行墙、草密度足够 | **未确认外部依赖** | 本月内拿田块负责人书面确认 + 物候预判；同时定备用验证区 | 启用替代地块；仍不足则触发下方降级包 |
| **10 月中芍药地上部仍基本完整（作物墙可提）** | **汇报人判断，未现场复核**（台账 Hw-22） | **S0 预检（09-21 复审后拆成两栏，见 §4.2）**：人眼看原图判作物/可通行带是否可见 ＋ 算法判能否可靠提线，两份结果都留 | 人工判"看不见"或算法连续失效 → 秋季 V2 不成立：改验证"垄沟/裸土通道提线"可行性，C1 图像照采，V2 落春季 |
| 4 周内能推进到"能下田沿行" | 未验证 | **门 N 链**推进：B1 烧录 → B2 对拍 → 导航专用安全三项（**不含 B5**，B5 属门 F），每过一项在缺口清单打勾 | 秋季预实验降级为"遥控 + 感知在线记录"，V2 自主项推春季 |
| 感知域差可修复（秋季微调后可用） | 未验证 | C2 后用留出集回放，按 §7 口径判有效双墙占比 | 经典 OpenCV 行线兜底通道作数据源 |
| 刀控 P0-7 可解锁 | 等实物 | 继电器板端子照片 | V3/V4 归因收窄为"固定刀条件下整机效果"（措辞已在 deck 预演） |

**C 路线降级包（重写，替代 v0.9 §9）**：春季主对照若落空，可依赖的是 秋季预实验（V2 真实记录）+ 台架（V3、故障响应、刀头对比）+ 离线感知（V1 分层与失效）；**必须删除**任何"田间全自主作业已验证""主动对刀改善除草效果"的头条结论，降为台架/受控验证 + 展望。是否满足送审由导师据最低包判定。

## 9. 风险台账（v1.0）

| # | 风险 | 影响 | 处置 |
|---|---|---|---|
| R1 | 春季班车仍未书面确认 | C 路线主实验落空 | §8 第一行；双窗口已建 |
| R2 | 刀控与滑台均未接入，V3/V4 无数据 | 第 4/5 章空心 | E4 + 12 月前解锁 |
| R3 | **挂草与撞石无负载感知，无法主动抬刀**（组会新暴露） | 刀变形、推杆烧毁、伤苗；且 10 mm/s 抬刀本身慢 | 机械卸载先上（不依赖传感）；电流判据待标定；组会征求导师意见 |
| R4 | 感知秋季域未验证 | V1/V2 无稳定输入 | C1/C2 优先 + OpenCV 兜底 |
| R5 | 送审前占位与图表未兑现 | 不能送审 | 4 月初封版硬门，逐 `<待补充>` 挂 owner |
| R6 | P 区未清完就被再评审抓到 | 可信度受损 | P 区优先级高于扩写 |

## 10. 待作者/导师确认（只留真正需要别人点头的）

1. 春季田块与物候的**书面**确认（§8）。
2. 挂草/撞石的主动抬刀走哪条：机械卸载先上，还是必须一步到位加行程测量（deck 第 15/16 页已作为组会讨论项）。
3. 伤苗率外层验收界（≤1% 还是 ≤3%）——影响 V4 口径冻结。
4. 鸭掌铲铲幅何时补测——不补则 ch05 组1 对比条件不对等。

## 11. 下一步（本 spec 批准后）

E1 两个 bug 修复批 → 交 zcode 审并 merge（领先提交数以 `git rev-list --count zcode/master..HEAD` 当场实测为准，不写死）→ E2 → P 区分批手术提交 → 秋季预实验测量协议单独成文（一页表，下田前定稿）。

## 12. 09-21 codex 复审处置记录（`D:\ai work\codex\docs\reviews\2026-09-21-project-thesis-review.md`）

九条发现，逐条对着代码/文件核实后：**8 条成立（其中 4 条是我的错），1 条成立且它说轻了**。

| 发现 | 核实 | 处置 |
|---|---|---|
| R1 秋季"抬刀空跑"无对应运行模式 | **成立**，`retrofit.c:244` 1=提刀，`main.py:211` AUTO 每帧发 `pack_tool(tool_mm, 0)` | §4.1 定义"导航验证模式"三条显式约束 + 禁止两种偷懒实现 + 抓帧验收 |
| R2 秋季范围与安全前置排期自相矛盾 | **成立**，我原文 B5 同时出现在秋季行与 1 月底行 | §4.1 拆成门 N／门 F 两张表（日期＋负责人＋证据），§7 重写 |
| R3 三带空间口径未统一 | **成立**（旧判定"≤60 cm 且必须压苗"已作废：同日 Hw-20 实测样机 2.15 m，60 cm 是硬错误；"必须压苗"又被 09-21 再次复审以 191=5×38.2 的反例撤回） | 开 `docs/整车尺寸实测表_20260921.md` + `tools/geometry_check.py`（只报事实，7 测试）；门 N 第一步从"量车"改为"**量田里横断面 M14/M15**" |
| R4 P 区仍是承诺 | **成立**，`be9093a` 后论文无新提交，Word 仍是 09-09 v14 | P1–P14 保持原序，但排在门 N 之后 |
| R5 指标不能只换一个数 | **成立** | P9 改为"冻结 checkpoint＋epoch＋成组指标"，禁止跨轮次拼数 |
| R6 V1–V4 缺可执行测量协议 | **成立** | 采前三件成文（分母／±5 cm 口径／记录字段）；总误差"分解"改称"分层验证与瓶颈分析"，不做 RMSE 相加 |
| R7 推杆位移 ≠ 刀尖离地 | **成立** | deck 第 15 页那句在论文侧不得继承；提刀时间按 M10 实测传动比算 |
| §5 第 12 页 PD 阻尼过度声明 | **成立，我的错** | `main.py:104` 用默认 `k_d=0.0`（`control.py:86` 注释自认"P-only until k_d set"）→ ė 只经时延补偿 `e+ėτ` 进入，**微分阻尼从未启用**。论文与后续材料改述为"P + 时延超前，k_d 未整定" |
| §5 B8 因果句证据不足 | **成立，我的错** | "包长增长即必走无线""5000 超时＝推流未启动"降级为推断；connect 超时更像被丢弃/防火墙，无人监听会立刻 refused。台账 B8 记录已改 |
| E1 修法（≥50 帧）不成立 | **成立，我的错** | 见 §6 E1①：改为"≥50 帧序号互不相同且单调递增"，且重新同步不恢复 AUTO、不清急停锁存；"永久拒绝"措辞更正 |

**它说对但当时我们无法接受的**：R3 只说"口径要统一"，而当时我判断"两个数最多一个真"。事后 Hw-20 实测车宽 2.15 m，`ch02:14` 直接被否掉，两难消失——说明我当时的"更严重"是在**错误前提上加码**。

**已被 09-21 再次复审撤回的本文原断言**："若 ≤60 cm 为真则车辆行驶轨迹本身压在作物行上"——不成立，且整个前提已废。**轮距 ÷ 行距 = 跨几个行距，推不出压苗**（行距 38.2 cm 时 191 cm 恰为 5 个行距，两轮正落在行间）。压苗与否要另查四项：轮迹对行线的横向偏差、胎宽、作物保护带、行驶跟踪误差（已列为 M14/M15）。

它按"跨 4 行"字面算 3s 跨度、未考虑大小行这一点仍成立，故 M3 要求实测连续 4 行中心距的最小/最大值来判定。

**状态提示**：本轮另发现组会 PPT 工作树有汇报人自己的未提交修改（`M docs/组会汇报_20260916/…pptx`）。下次改 deck 前必须先重读现文件，不得用 plan 覆盖。
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

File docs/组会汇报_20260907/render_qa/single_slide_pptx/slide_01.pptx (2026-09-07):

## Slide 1

纯视觉芍药行间除草机器人

方案设计与研究进展汇报

面向中草药零农残要求的机械中耕方案

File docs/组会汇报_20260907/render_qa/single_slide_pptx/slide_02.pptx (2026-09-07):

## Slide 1

研究背景

研究问题：行间除草不伤苗，且不依赖 RTK

1. 芍药林下种植要求零农残，化学除草不可用
2. 底盘跨 4 行芍药，一次作业清除 3 条行间草带
3. 不使用 GNSS/RTK，导航与对行完全依赖单目相机
4. 目标：0.5 km/h 作业，除草率≥80%，伤苗率≤1%
5. 株间除草不在范围内，只做行间（绕开单株识别难题）

总体方案

理论方法

试验设计

进度与计划

纯视觉芍药行间除草机器人 · 组会进展汇报 · 2026-09-07

2

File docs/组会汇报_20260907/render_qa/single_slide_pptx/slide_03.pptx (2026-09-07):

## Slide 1

研究背景

系统闭环：相机到执行的五段数据流

总体方案

理论方法

试验设计

进度与计划

相机采集推流

PC 分割+中心线

导航与刀控

UDP 下发执行

→

→

→

1. 闭环目标周期 50-100ms
2. 车端只采集执行，PC 集中决策
3. 三级看门狗兜底安全

纯视觉芍药行间除草机器人 · 组会进展汇报 · 2026-09-07

3

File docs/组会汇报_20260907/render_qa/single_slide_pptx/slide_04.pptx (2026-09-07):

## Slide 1

研究背景

四个关键决策均已论证并固化为设计基线

总体方案

理论方法

试验设计

进度与计划

刀头

鸭掌铲主选 + 弹齿对比：除草率与伤苗率的权衡

算力

PC 集中计算：一期固定算力变量，验证方法本身

线控

固件 SBUS/UDP 双指令源：遥控保留为备份通道

四轮差速滑移转向：与实车四轮独立驱动一致

运动学

纯视觉芍药行间除草机器人 · 组会进展汇报 · 2026-09-07

4

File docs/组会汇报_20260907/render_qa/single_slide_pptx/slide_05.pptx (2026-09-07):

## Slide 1

研究背景

理论一：单目视觉双墙约束的对行方法

1. 分割出左右行墙，各自最小二乘拟合 x = a·y + b
2. 中心线取两墙加权中点，权重按拟合内点率门控
3. 遮挡场景引入像素密度偏置，改用按行投票裁剪拟合
4. 消融验证：稠密遮挡下中心线误差 25.5px 降至 0.5px
5. 远场中心线供底盘导航，近场供中间刀，双预视点分工

总体方案

理论方法

试验设计

进度与计划

纯视觉芍药行间除草机器人 · 组会进展汇报 · 2026-09-07

5

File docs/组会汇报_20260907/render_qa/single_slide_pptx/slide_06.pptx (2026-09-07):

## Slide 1

研究背景

理论二：差速底盘横向误差模型与 PD 控制

1. 运动学：v=(vR+vL)/2，ω=(vR−vL)/W_eff（滑移转向）
2. 横向误差动态：ė = v·ψ，ψ̇ = 2Δv/W_eff
3. 控制量 Δv = k_p·e + k_d·ė，闭环三阶可作稳定性分析
4. 执行滞后 τ≈0.1s 时 k_lat 上限由相位裕度反算
5. 轮速由 TIM3 输入捕获实测，打滑系数田间标定修正

总体方案

理论方法

试验设计

进度与计划

纯视觉芍药行间除草机器人 · 组会进展汇报 · 2026-09-07

6

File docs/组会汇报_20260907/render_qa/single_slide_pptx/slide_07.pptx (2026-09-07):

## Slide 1

研究背景

理论三：无线链路时延的前馈补偿

1. 补偿律：e_exec = e_meas + ė·τ，开环前馈不改特征方程
2. 时延统计取滚动中位数，对 Wi-Fi 重尾分布稳健
3. p95 超过 50ms 触发告警，500ms 断链强制急停
4. 可验证预言：关补偿时 RMS 偏差恶化量应正比于 τ·v
5. 补偿置于工程实现章节，方法贡献聚焦在对行本身

总体方案

理论方法

试验设计

进度与计划

纯视觉芍药行间除草机器人 · 组会进展汇报 · 2026-09-07

7

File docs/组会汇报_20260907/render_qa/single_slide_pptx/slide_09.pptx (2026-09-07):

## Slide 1

研究背景

创新点定稿：方法为核心，装置为载体

总体方案

理论方法

试验设计

进度与计划

创新点1

三刀装置 + 双墙约束主动对行方法（核心）

创新点2

限深仿形机构设计与刀头对比优化

后备点3

时延前馈补偿，视试验显著性决定升格

主动 vs 固定刀对比试验直接验证方法

证据

纯视觉芍药行间除草机器人 · 组会进展汇报 · 2026-09-07

9

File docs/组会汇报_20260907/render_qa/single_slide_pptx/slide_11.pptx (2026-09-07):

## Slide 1

研究背景

代码与固件侧交付已全部完成

总体方案

理论方法

试验设计

进度与计划

算法

感知/控制/状态机/协议全链路，35 项测试通过

固件

双指令源+三级看门狗，Keil 编译 0 错误

安全

驱动门控接入真实路径，急停帧显式下发

外部 12 条意见逐条采纳/驳回并留档

评审

纯视觉芍药行间除草机器人 · 组会进展汇报 · 2026-09-07

11

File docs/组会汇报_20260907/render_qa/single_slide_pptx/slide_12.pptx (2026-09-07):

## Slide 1

研究背景

当前瓶颈在实物侧，不在算法侧

1. 待办：固件烧录、串口对拍、接线与三项系数标定
2. 待购：RDK X5 网关、CP2102×2、TB6600、CPE 网桥一对
3. 域差异风险已实测：夏季模型在当前田况过分割
4. 对策：10 月中前补采 200-300 张秋季样本并微调
5. 采集清单已定稿：光照×行况×视角矩阵，含密度分级标准

总体方案

理论方法

试验设计

进度与计划

纯视觉芍药行间除草机器人 · 组会进展汇报 · 2026-09-07

12

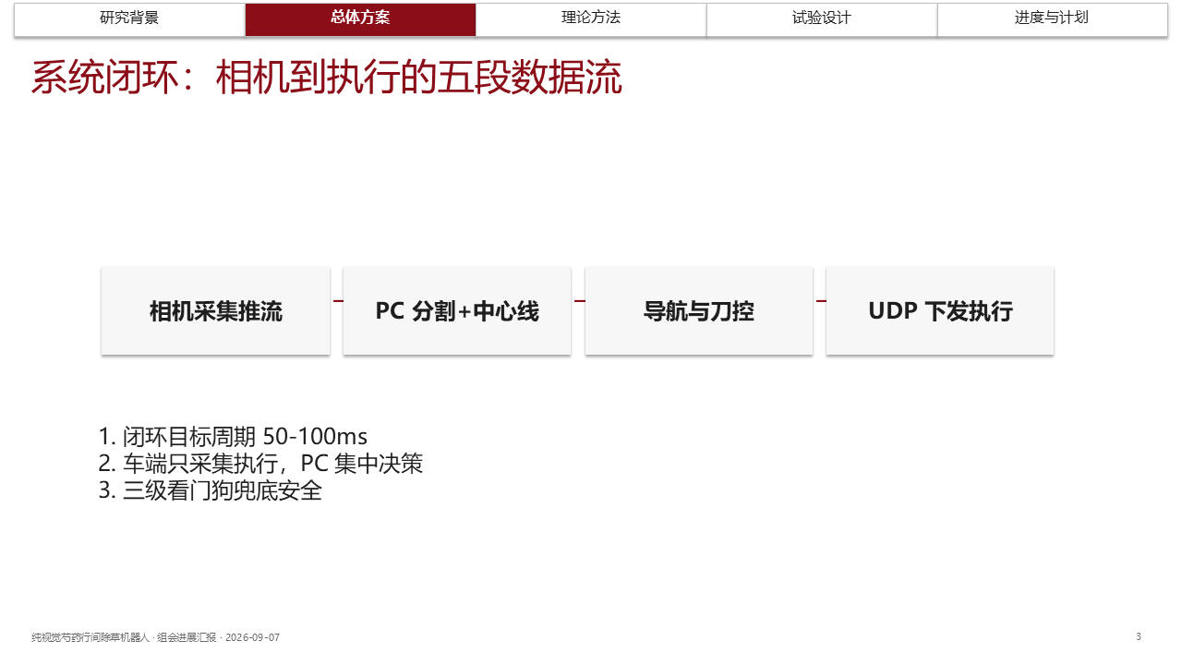
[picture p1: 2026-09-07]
docs/组会汇报_20260907/render_qa/png3/s03.png

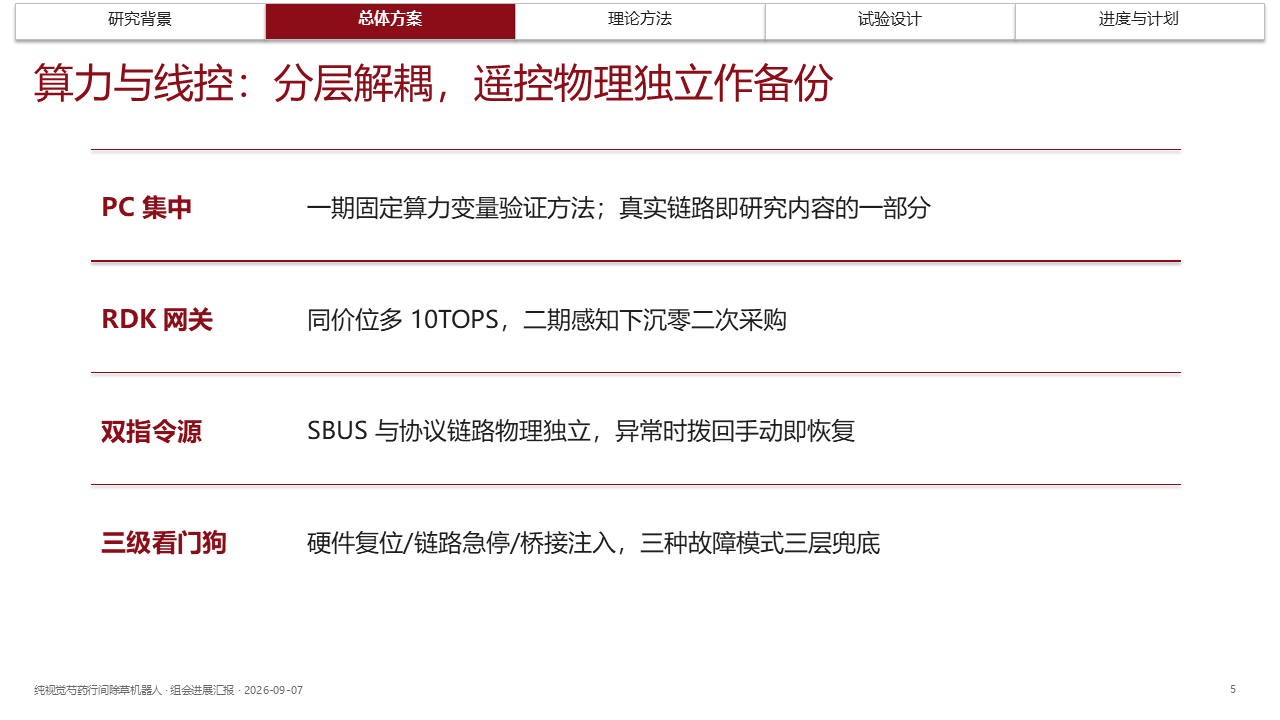
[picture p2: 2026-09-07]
docs/组会汇报_20260907/render_qa/png3/s05.png

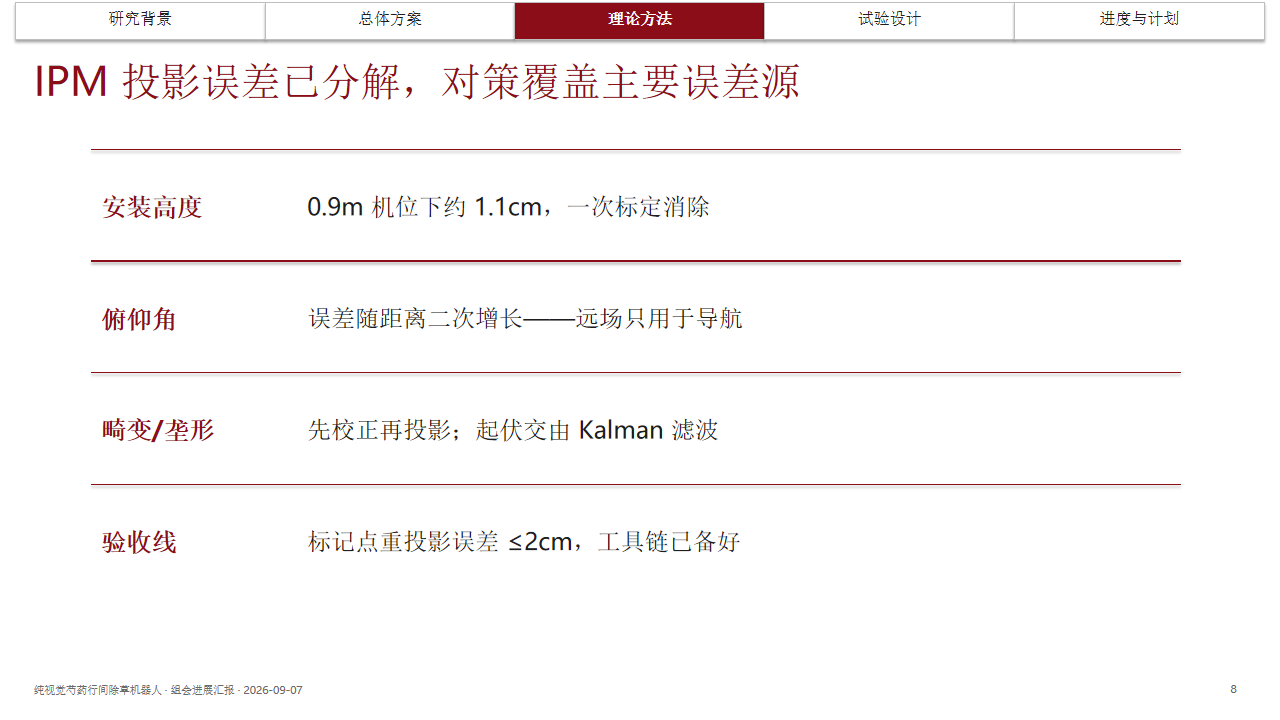
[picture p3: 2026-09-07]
docs/组会汇报_20260907/render_qa/png/slide_08.png

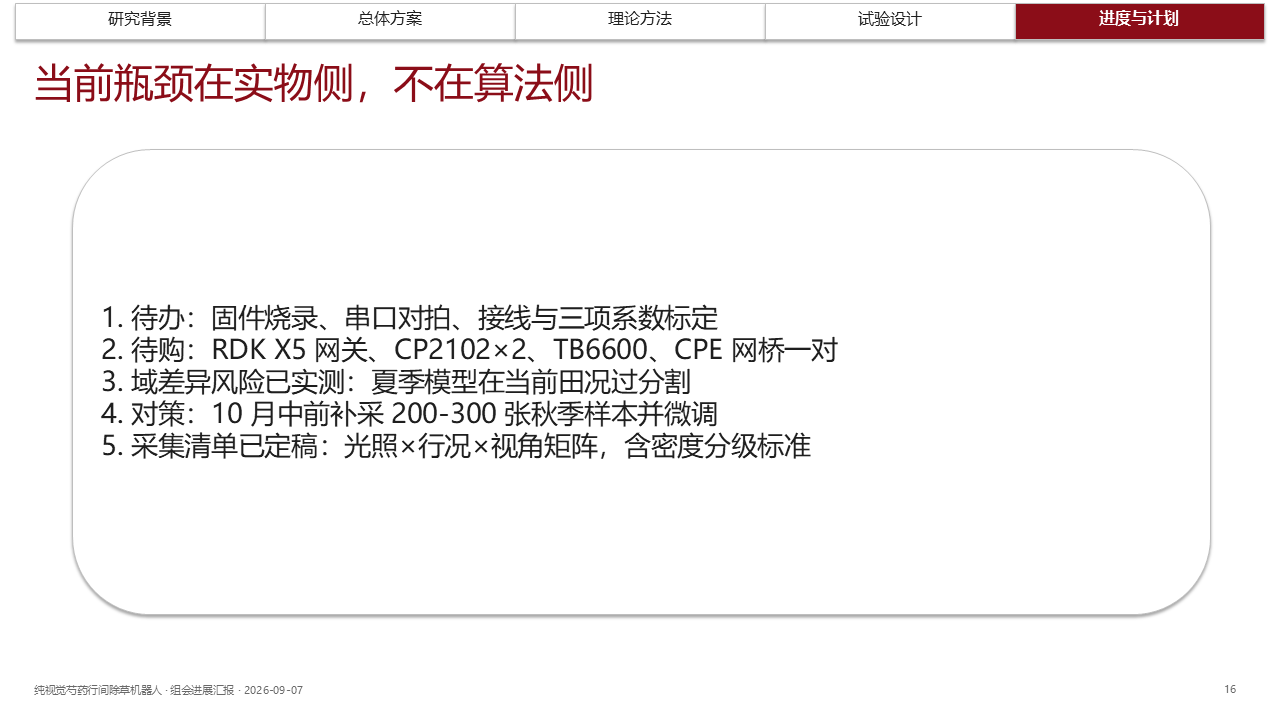
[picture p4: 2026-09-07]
docs/组会汇报_20260907/render_qa/png3/s16.png

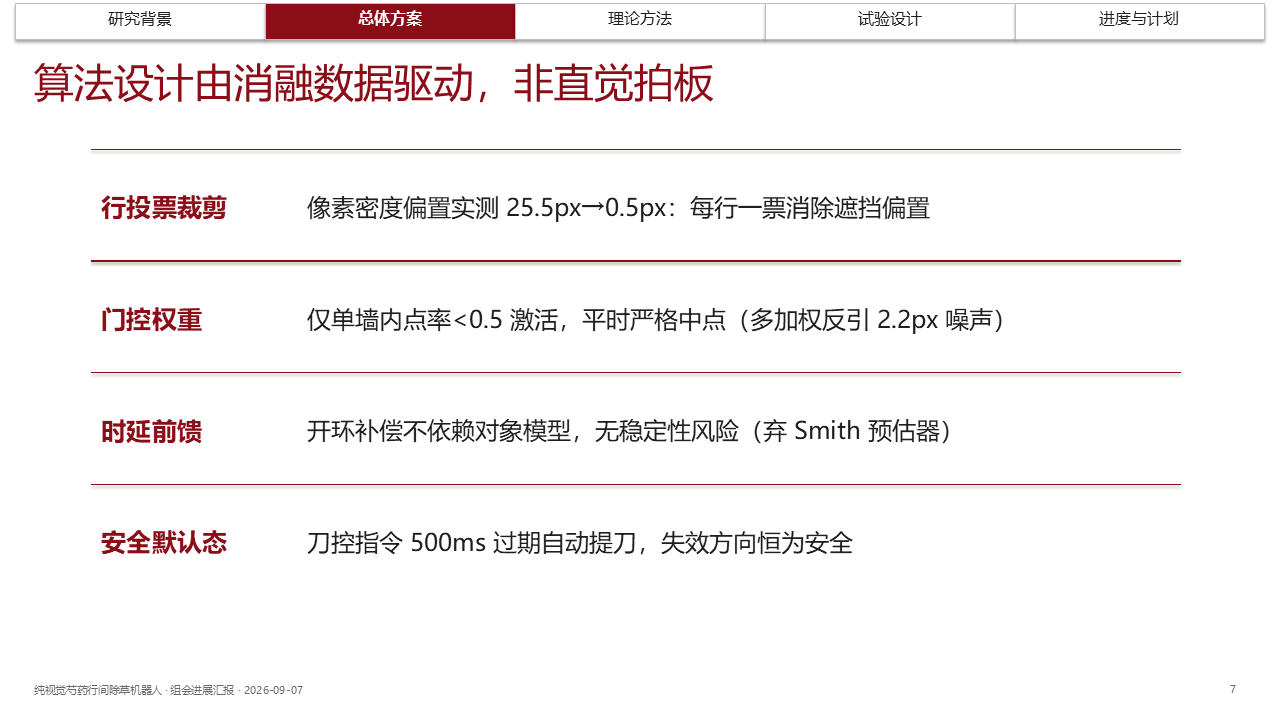
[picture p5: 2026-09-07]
docs/组会汇报_20260907/render_qa/png3/s07.png

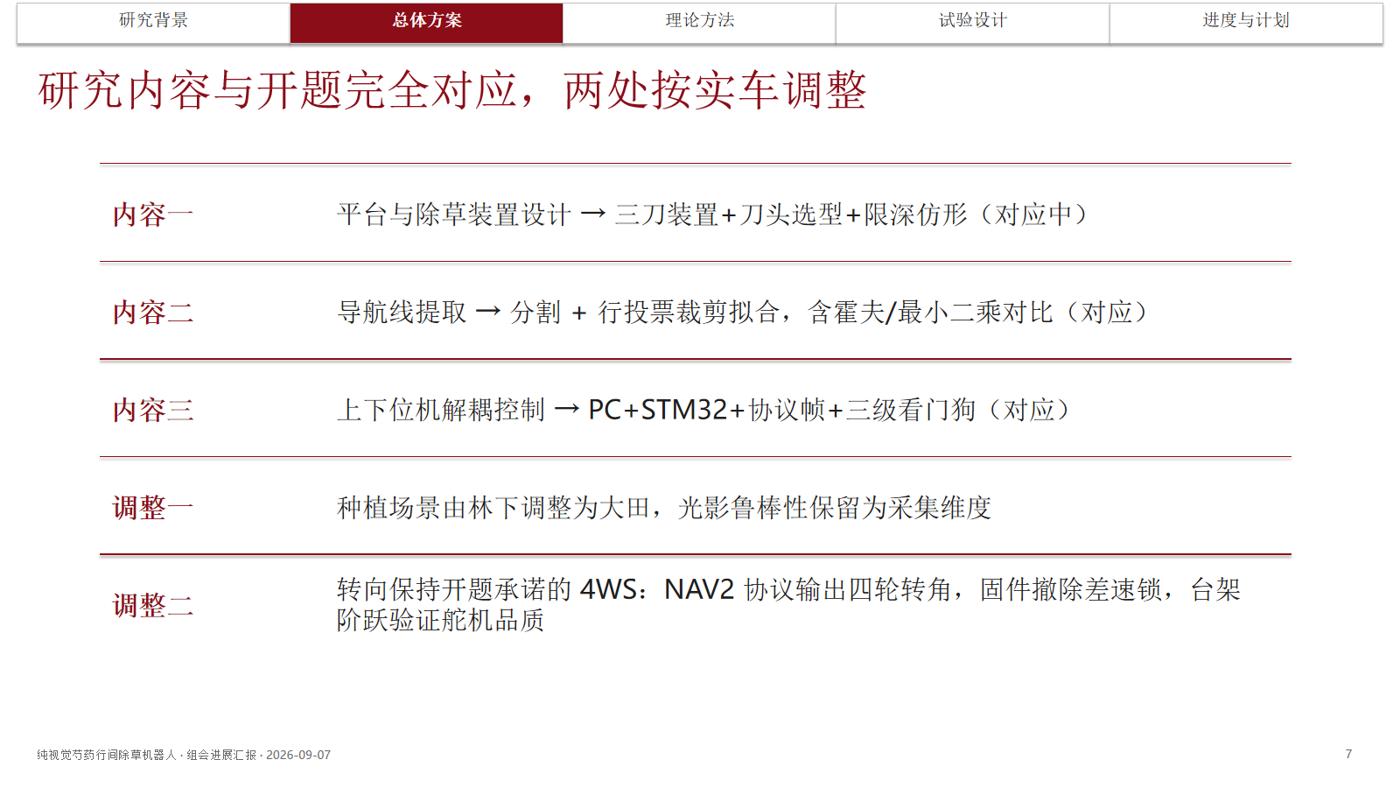
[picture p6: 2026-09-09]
docs/组会汇报_20260907/render_qa/png4/幻灯片7.png

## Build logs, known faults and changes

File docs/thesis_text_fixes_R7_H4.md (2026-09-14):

# 论文文本改动清单（R7 / H4，2026-09-14）— 待授权应用到 chucao_prj

> 目标文件：`D:\JetBrains\chucao_prj\thesis_cau\03_chapters\ch03_draft.md`、`ch04_draft.md`、`ch02_draft.md`
> 依据：v0.9 §3.1（R4 定案：前轮 Ackermann + 后轮=0）、复审 09-14 R7、台账 Hw-7（中间刀=伺服非步进）、Hw-11（轮角反馈待核实）。
> **状态：本清单在 qoder 侧；chucao_prj 标"只读"，未擅自改。用户点头后由我或 zcode 落库。**
> 改完全库 grep 复核：`后轮反向|反向偏转|步进电机|NEMA17|NAV2.*下发|epoch 201|峰值` 应无残留（显式调整声明除外）。

---

## A. ch04 §4WS 阿克曼运动学建模（第 16–32 行）—— 与 R4 修后代码一致

**A1 第 16 行**：
- 旧：`…四个车轮绕同一瞬时转动中心（ICC）转动的阿克曼几何成立。`
- 新：`…前轮按阿克曼几何绕同一瞬时转动中心（ICC）转动，后轮保持直行（转角为 0）。`

**A2 第 20 行**：
- 旧：`四轮转角按阿克曼几何分配：前外轮与后轮（后轮反向偏转）分别为`
- 新：`前轮转角按阿克曼几何分配，后轮转角恒为 0：`

**A3 第 24 行（后轮反相公式，R4 的错源）**：
- 旧：`[[EQ:\delta_{rl}=-\arctan\frac{L}{R-B_r/2},\quad \delta_{rr}=-\arctan\frac{L}{R+B_r/2}]]`
- 新：`[[EQ:\delta_{rl}=\delta_{rr}=0]]`

**A4 第 26–30 行**：后轮半径式 `R-B_r/2 / R+B_r/2` **保留**（后轮直行时其到 ICC 半径仍是该值，与 `nav_control.py` 修后一致）。第 30 行 NAV2 由**现在时→设计/待实现**：
- 旧：`导航控制帧（NAV2）下发的即为四轮目标转角与中心速度 v：车载固件将目标角经斜率限幅写入转向舵机，并按上式将中心速度映射为四轮目标转速，进入既有 PID 速度环。`
- 新：`导航控制帧（NAV2，本协议为设计、待实现）下发前轮目标转角与中心速度 v，后轮目标角置 0；固件将目标角经斜率限幅写入前转向舵机，并按上式把中心速度映射为四轮目标转速，进入既有 PID 速度环。`

**A5 第 32 行（转向失效检测）**：标"待实现 + 反馈前置"：
- 旧：`同时固件利用转向角反馈实现转向失效检测（指令角与反馈角偏差超阈值持续超时即触发减速、提刀、停车）…`
- 新：`并规划由固件依据转向角反馈实现转向失效检测（指令角与反馈角偏差超阈值持续超时即减速、提刀、停车）；该检测依赖 MCU 可读取的轮角反馈信号，其可得性待核实（台账 Hw-11：原车外部轮角采样链是否退役、伺服内部闭环能否读回）。`

---

## B. ch04 §中间刀对行 + ch02 §除草装置 —— 步进 → 伺服（Hw-7）

**B1 ch04 第 60 行**：
- 旧：`中间刀横向滑轨由步进电机驱动…执行机构运动学分辨率为 s/(200N_s)（s 为丝杠导程 8 mm，N_s 为细分数）…`
- 新：`中间刀横向滑轨由 48V 直流伺服（位置模式，电子齿轮等效脉冲）经滚珠丝杠（导程 8 mm）驱动…横向分辨率由伺服编码器与电子齿轮决定，远高于 ±2 cm 对行需求，控制精度瓶颈在感知端而非执行端。`（删"200N_s 细分数"式）

**B2 ch02 §除草装置总体布置**：`NEMA17 步进电机` → `48V 直流伺服（与转向同型）`；快换/导轨描述不变。台账 Hw-7/Hw-12 为依据。

---

## C. ch03 §分割模型训练与评估 —— mIoU 峰值口径（复审 R7）

- 旧：`第 201 轮取得峰值 mIoU 0.7163…`
- 新：`第 201 轮 mIoU 0.7163（该阶段精调末值）；全程验证集峰值为第 76 轮 0.7459（见训练日志）。` —— 不再把 201 轮称"全程峰值"。

---

## D. 一致性收尾
- ch02 §系统总体架构 / 表 2-2 若仍含"滑移转向/无转向机构"→ 改 4WD-4WS（前轮转向 + 后轮回正），并保留"前期曾误判、据固件核对修正、与开题一致"的显式调整声明。
- 摘要/结论若提"四轮转向控制"→ 与"前轮转向 + 后轮回正"口径统一。

*本清单为纯文本 before→after，套用时逐条 diff 即可；应用方：用户授权后 qoder 或 zcode 落 chucao_prj。*

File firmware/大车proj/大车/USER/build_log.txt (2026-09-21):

*** Using Compiler 'V5.06 update 5 (build 528)', folder: 'D:\ruanjian\keil\KEIL32\ARM\ARMCC\Bin'
Rebuild target 'PWM'
compiling beep.c...
compiling key.c...
compiling can.c...
compiling adc.c...
compiling stm32f4xx_it.c...
compiling led.c...
..\HARDWARE\LED\led.c(401): warning:  #550-D: variable "switch_ch"  was set but never used
  	u8 switch_ch; 
..\HARDWARE\LED\led.c(477): warning:  #223-D: function "printf" declared implicitly
  				printf("左前左转限位卡住:\r\n");
..\HARDWARE\LED\led.c(484): warning:  #223-D: function "printf" declared implicitly
  				printf("左前右转限位卡住:\r\n");
..\HARDWARE\LED\led.c(489): warning:  #223-D: function "printf" declared implicitly
  				printf("右前左转限位卡住:\r\n");
..\HARDWARE\LED\led.c(494): warning:  #223-D: function "printf" declared implicitly
  				printf("右前右转限位卡住:\r\n");
..\HARDWARE\LED\led.c(499): warning:  #223-D: function "printf" declared implicitly
  				printf("左后左转限位卡住:\r\n");
..\HARDWARE\LED\led.c(504): warning:  #223-D: function "printf" declared implicitly
  				printf("左后右转限位卡住:\r\n");
..\HARDWARE\LED\led.c(509): warning:  #223-D: function "printf" declared implicitly
  				printf("右后左转限位卡住:\r\n");
..\HARDWARE\LED\led.c(514): warning:  #223-D: function "printf" declared implicitly
  				printf("右后右转限位卡住:\r\n");
..\HARDWARE\LED\led.c(527): warning:  #940-D: missing return statement at end of non-void function "Touch_detection" 
  }
..\HARDWARE\LED\led.c: 10 warnings, 0 errors
compiling system_stm32f4xx.c...
compiling exti.c...
..\HARDWARE\EXTI\exti.c(45): warning:  #177-D: variable "flag_exti"  was declared but never referenced
  {  static u8 flag_exti=0;
..\HARDWARE\EXTI\exti.c(139): warning:  #1-D: last line of file ends without a newline
  }
..\HARDWARE\EXTI\exti.c: 2 warnings, 0 errors
compiling pwm.c...
compiling main.c...
..\HARDWARE\uart2\uart2.h(9): warning:  #1295-D: Deprecated declaration set_adresss - give arg types
  void set_adresss();
..\HARDWARE\uart2\uart2.h(12): warning:  #1295-D: Deprecated declaration get_angle_encode - give arg types
  void get_angle_encode();
main.c(97): warning:  #177-D: variable "wheel_angle_limit"  was declared but never referenced
    double wheel_angle_limit=0.420;     //2.5度  定义车轮转向的机械极限角度 0.0175    25         
main.c(110): warning:  #177-D: variable "t"  was declared but never referenced
  	int i=0,t,count,j,stop,stop_count,upload_count,only_start=0,stop_voltage_count=0;
main.c(110): warning:  #177-D: variable "stop"  was declared but never referenced
  	int i=0,t,count,j,stop,stop_count,upload_count,only_start=0,stop_voltage_count=0;
main.c(110): warning:  #177-D: variable "upload_count"  was declared but never referenced
  	int i=0,t,count,j,stop,stop_count,upload_count,only_start=0,stop_voltage_count=0;
main.c(110): warning:  #550-D: variable "stop_voltage_count"  was set but never used
  	int i=0,t,count,j,stop,stop_count,upload_count,only_start=0,stop_voltage_count=0;
main.c(111): warning:  #177-D: variable "shacheccr"  was declared but never referenced
  	int shacheccr = 490;
main.c(116): warning:  #177-D: variable "wheel_Angle_correct_run"  was declared but never referenced
  	double wheel_Angle_correct_run[4]={0,0,0,0};  // 0左前，1右前，2左后，3右后，运行中归正（回中间）
main.c(119): warning:  #177-D: variable "real_time_erro"  was declared but never referenced
  	double  real_time_erro=0.0175*2;               //为1度    运行中大于这个角度，才修正
main.c: 10 warnings, 0 errors
compiling lcd.c...
compiling sensor.c...
compiling CRC2.c...
compiling telecontrol.c...
..\HARDWARE\telecontrol\telecontrol.c(127): warning:  #550-D: variable "t"  was set but never used
  	int i,t;
..\HARDWARE\telecontrol\telecontrol.c: 1 warning, 0 errors
compiling work_control.c...
compiling uart2.c...
..\HARDWARE\uart2\uart2.h(9): warning:  #1295-D: Deprecated declaration set_adresss - give arg types
  void set_adresss();
..\HARDWARE\uart2\uart2.h(12): warning:  #1295-D: Deprecated declaration get_angle_encode - give arg types
  void get_angle_encode();
..\HARDWARE\uart2\uart2.c(21): warning:  #177-D: variable "CRC_7"  was declared but never referenced
  	unsigned short int CRC_7;
..\HARDWARE\uart2\uart2.c(65): warning:  #167-D: argument of type "char *" is incompatible with parameter of type "u8 *"
  	  RS485_Send_Data(ByteSend2,8);//发送5个字节
..\HARDWARE\uart2\uart2.c(70): warning:  #167-D: argument of type "u8 *" is incompatible with parameter of type "char *"
  		    temp_send=Crc16withTable(&RS485_RX_BUF[0],5); //计算出校验码
..\HARDWARE\uart2\uart2.c(42): warning:  #177-D: variable "i"  was declared but never referenced
  		int i=0;
..\HARDWARE\uart2\uart2.c(138): warning:  #167-D: argument of type "char *" is incompatible with parameter of type "u8 *"
  	  RS485_Send_Data(ByteSend2,8);//发送8个字节
..\HARDWARE\uart2\uart2.c(147): warning:  #167-D: argument of type "u8 *" is incompatible with parameter of type "char *"
  			temp_send=Crc16withTable(&RS485_RX_BUF[0],5); //计算出校验码
..\HARDWARE\uart2\uart2.c(110): warning:  #177-D: variable "i"  was declared but never referenced
  		int i=0;
..\HARDWARE\uart2\uart2.c(202): warning:  #167-D: argument of type "char *" is incompatible with parameter of type "u8 *"
  	  RS485_Send_Data(ByteSend2,8);//发送8个字节
..\HARDWARE\uart2\uart2.c(209): warning:  #167-D: argument of type "u8 *" is incompatible with parameter of type "char *"
  		    temp_send=Crc16withTable(&RS485_RX_BUF[0],9); //计算出校验码
..\HARDWARE\uart2\uart2.c(180): warning:  #177-D: variable "i"  was declared but never referenced
  	int i=0;
..\HARDWARE\uart2\uart2.c(260): warning:  #167-D: argument of type "char *" is incompatible with parameter of type "u8 *"
  	  RS485_Send_Data(ByteSend2,8);//发送8个字节
..\HARDWARE\uart2\uart2.c(265): warning:  #167-D: argument of type "u8 *" is incompatible with parameter of type "char *"
  			temp_send=Crc16withTable(&RS485_RX_BUF[0],5); //计算出校验码
..\HARDWARE\uart2\uart2.c(301): warning:  #167-D: argument of type "char *" is incompatible with parameter of type "u8 *"
  	  RS485_Send_Data(ByteSend2,8);//发送8个字节
..\HARDWARE\uart2\uart2.c(305): warning:  #167-D: argument of type "u8 *" is incompatible with parameter of type "char *"
  		  temp_send=Crc16withTable(&RS485_RX_BUF[0],9); //计算出校验码
..\HARDWARE\uart2\uart2.c(236): warning:  #177-D: variable "i"  was declared but never referenced
  		int i=0;
..\HARDWARE\uart2\uart2.c(357): warning:  #167-D: argument of type "char *" is incompatible with parameter of type "u8 *"
  	  RS485_Send_Data(ByteSend2,8);//发送5个字节
..\HARDWARE\uart2\uart2.c(334): warning:  #177-D: variable "i"  was declared but never referenced
  		int i=0;
..\HARDWARE\uart2\uart2.c(386): warning:  #167-D: argument of type "char *" is incompatible with parameter of type "u8 *"
  	  RS485_Send_Data(ByteSend2,8);//发送5个字节
..\HARDWARE\uart2\uart2.c(363): warning:  #177-D: variable "i"  was declared but never referenced
  		int i=0;
..\HARDWARE\uart2\uart2.c: 21 warnings, 0 errors
compiling iwdg.c...
compiling uart5.c...
..\HARDWARE\uart2\uart2.h(9): warning:  #1295-D: Deprecated declaration set_adresss - give arg types
  void set_adresss();
..\HARDWARE\uart2\uart2.h(12): warning:  #1295-D: Deprecated declaration get_angle_encode - give arg types
  void get_angle_encode();
..\HARDWARE\uart5\uart5.c(89): warning:  #177-D: variable "RecState"  was declared but never referenced
  	static int RecState=0;    //静态整型变量用来解析帧头
..\HARDWARE\uart5\uart5.c(90): warning:  #177-D: variable "JiaQianState"  was declared but never referenced
  	static int JiaQianState=0;
..\HARDWARE\uart5\uart5.c(91): warning:  #177-D: variable "JiannQianState"  was declared but never referenced
  	static int JiannQianState=0; 
..\HARDWARE\uart5\uart5.c: 5 warnings, 0 errors
compiling uart4.c...
..\HARDWARE\uart2\uart2.h(9): warning:  #1295-D: Deprecated declaration set_adresss - give arg types
  void set_adresss();
..\HARDWARE\uart2\uart2.h(12): warning:  #1295-D: Deprecated declaration get_angle_encode - give arg types
  void get_angle_encode();
..\HARDWARE\uart4\uart4.c(406): warning:  #167-D: argument of type "u8 *" is incompatible with parameter of type "char *"
  						crc=Crc16withTable(buf,len-2);       //计算CRC校验值，出去CRC校验值
..\HARDWARE\uart4\uart4.c(857): warning:  #223-D: function "UartRxMonitor" declared implicitly
  		UartRxMonitor(1); ////串口接收监控
..\HARDWARE\uart4\uart4.c: 4 warnings, 0 errors
assembling startup_stm32f40_41xxx.s...
compiling path_plan.c...
..\HARDWARE\path_plan\path_plan.c(143): warning:  #177-D: variable "j"  was declared but never referenced
  	u8 j=0;
..\HARDWARE\path_plan\path_plan.c(787): warning:  #177-D: variable "W"  was declared but never referenced
  double R=0,W=0;
..\HARDWARE\path_plan\path_plan.c(851): warning:  #177-D: variable "W"  was declared but never referenced
  	double R=0,W=0;
..\HARDWARE\path_plan\path_plan.c: 3 warnings, 0 errors
compiling iic.c...
compiling uart3.c...
..\HARDWARE\UART3\uart3.c(130): warning:  #940-D: missing return statement at end of non-void function "rs485_UartWrite" 
  }
..\HARDWARE\UART3\uart3.c(151): warning:  #167-D: argument of type "u8 *" is incompatible with parameter of type "char *"
  			crc=Crc16withTable(buf,len-2);       //计算CRC校验值，出去CRC校验值temp_send=	Crc16withTable( &ByteSend2[0],11);
..\HARDWARE\UART3\uart3.c(243): warning:  #167-D: argument of type "u8 *" is incompatible with parameter of type "char *"
  			    crc=Crc16withTable(buf,len);           //计算CRC校验值
..\HARDWARE\UART3\uart3.c(139): warning:  #550-D: variable "num"  was set but never used
  	static u8 len,num; //num位寄存器的数量
..\HARDWARE\UART3\uart3.c: 4 warnings, 0 errors
compiling delay.c...
compiling sys.c...
compiling usart.c...
compiling misc.c...
compiling stm32f4xx_gpio.c...
compiling stm32f4xx_usart.c...
compiling stm32f4xx_syscfg.c...
compiling stm32f4xx_tim.c...
compiling protocol.c...
compiling stm32f4xx_fsmc.c...
compiling stm32f4xx_can.c...
compiling stm32f4xx_rcc.c...
compiling stm32f4xx_exti.c...
compiling stm32f4xx_dma.c...
compiling stm32f4xx_adc.c...
compiling stm32f4xx_iwdg.c...
compiling retrofit.c...
linking...
Program Size: Code=44848 RO-data=1152 RW-data=1076 ZI-data=3068  
FromELF: creating hex file...
"..\OBJ\PWM.axf" - 0 Error(s), 60 Warning(s).
Build Time Elapsed:  00:00:06

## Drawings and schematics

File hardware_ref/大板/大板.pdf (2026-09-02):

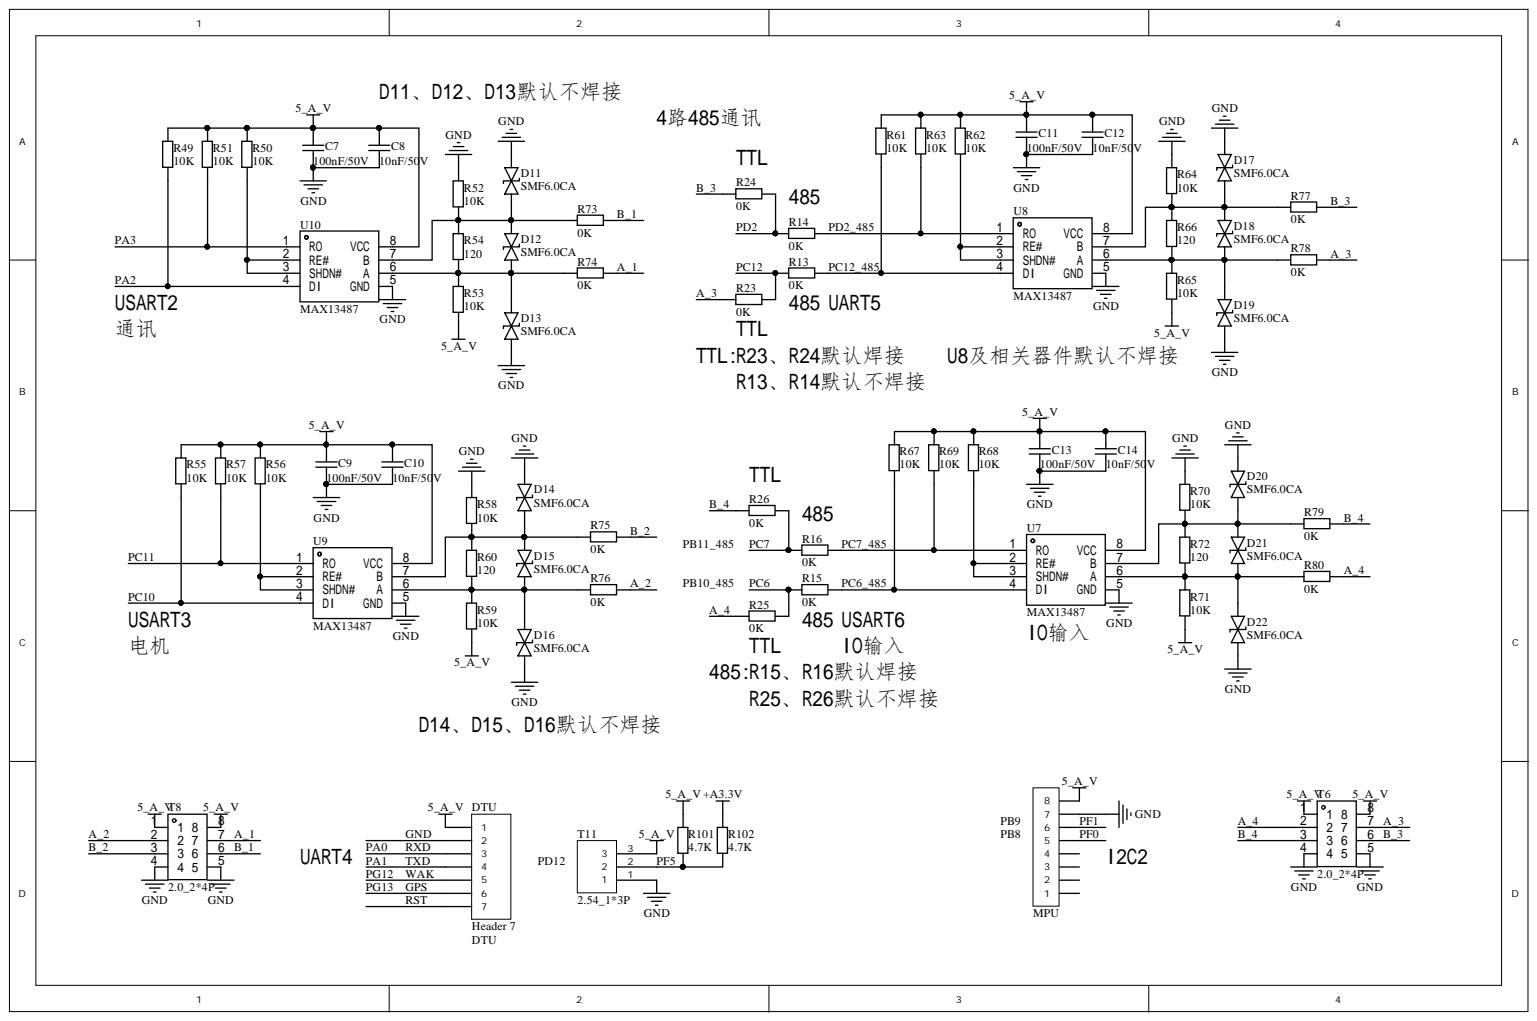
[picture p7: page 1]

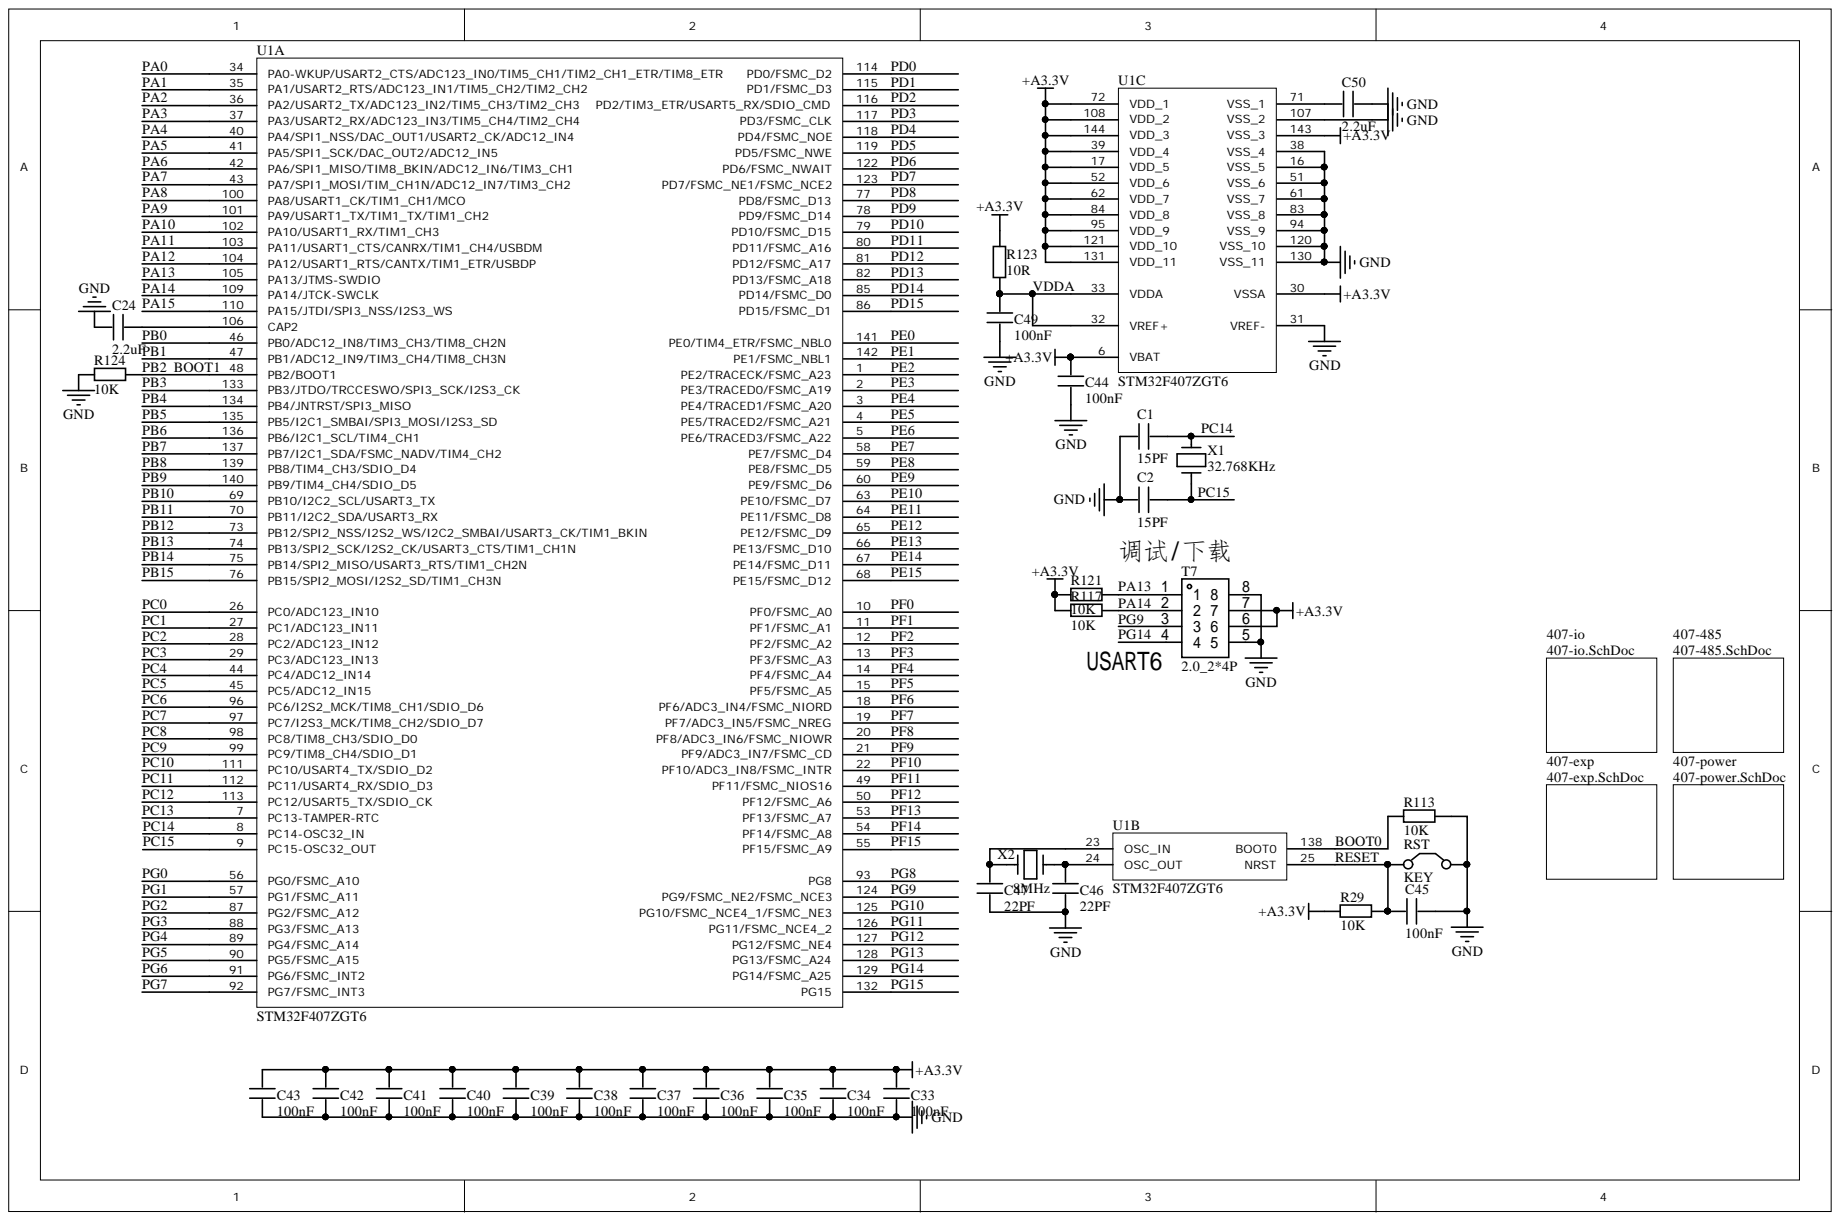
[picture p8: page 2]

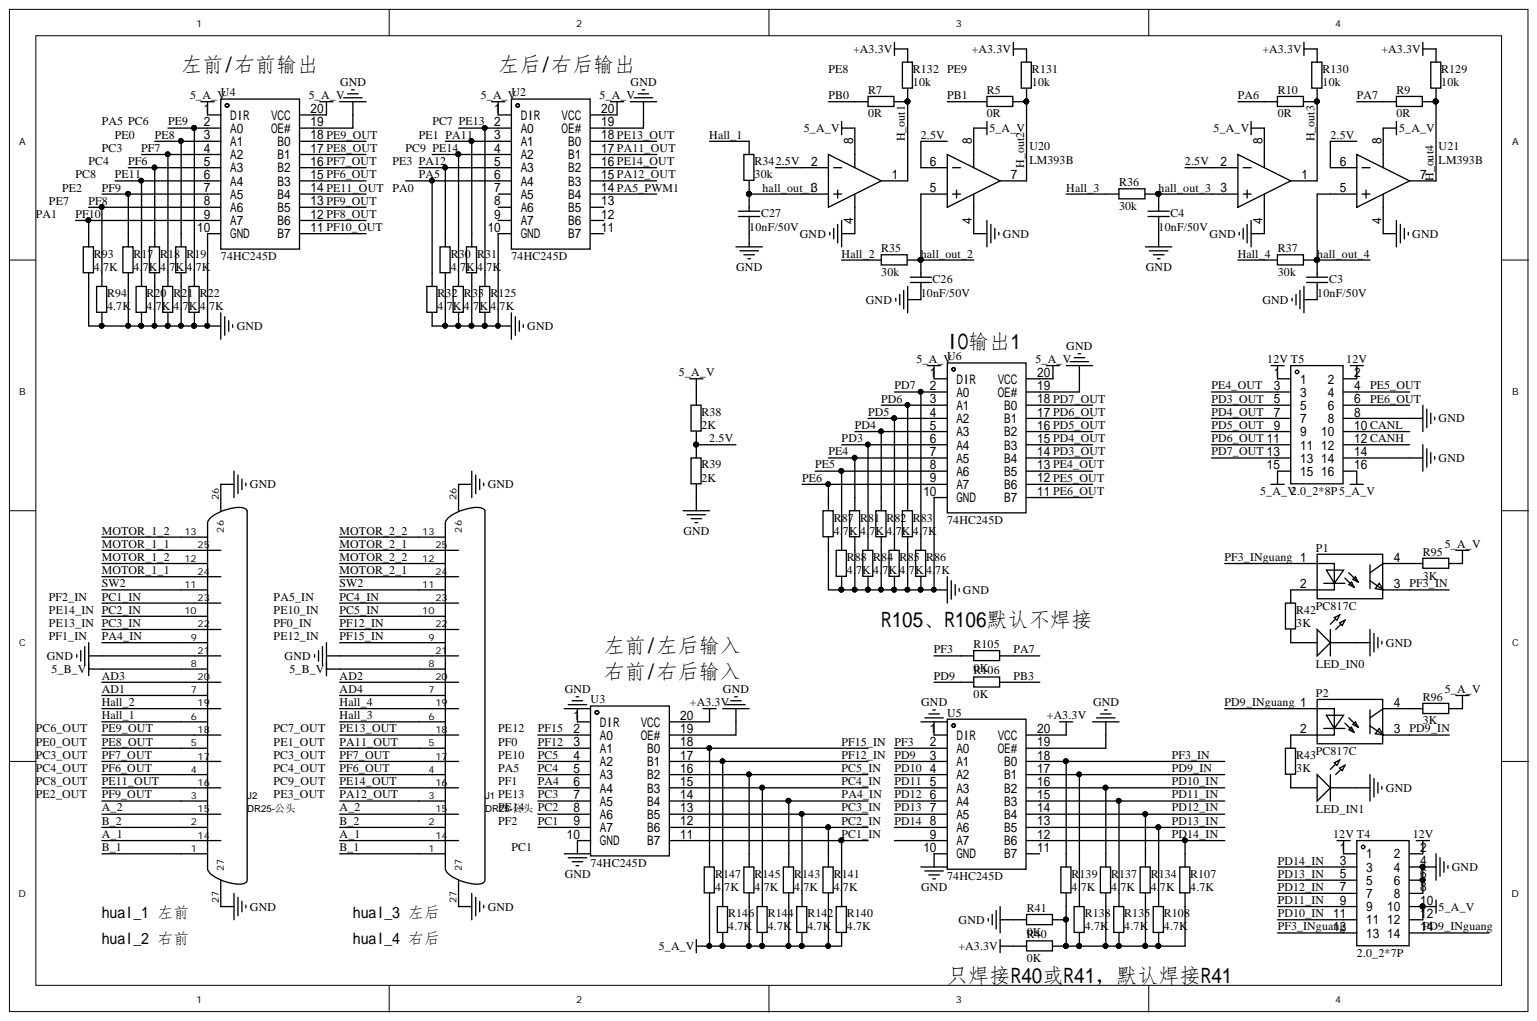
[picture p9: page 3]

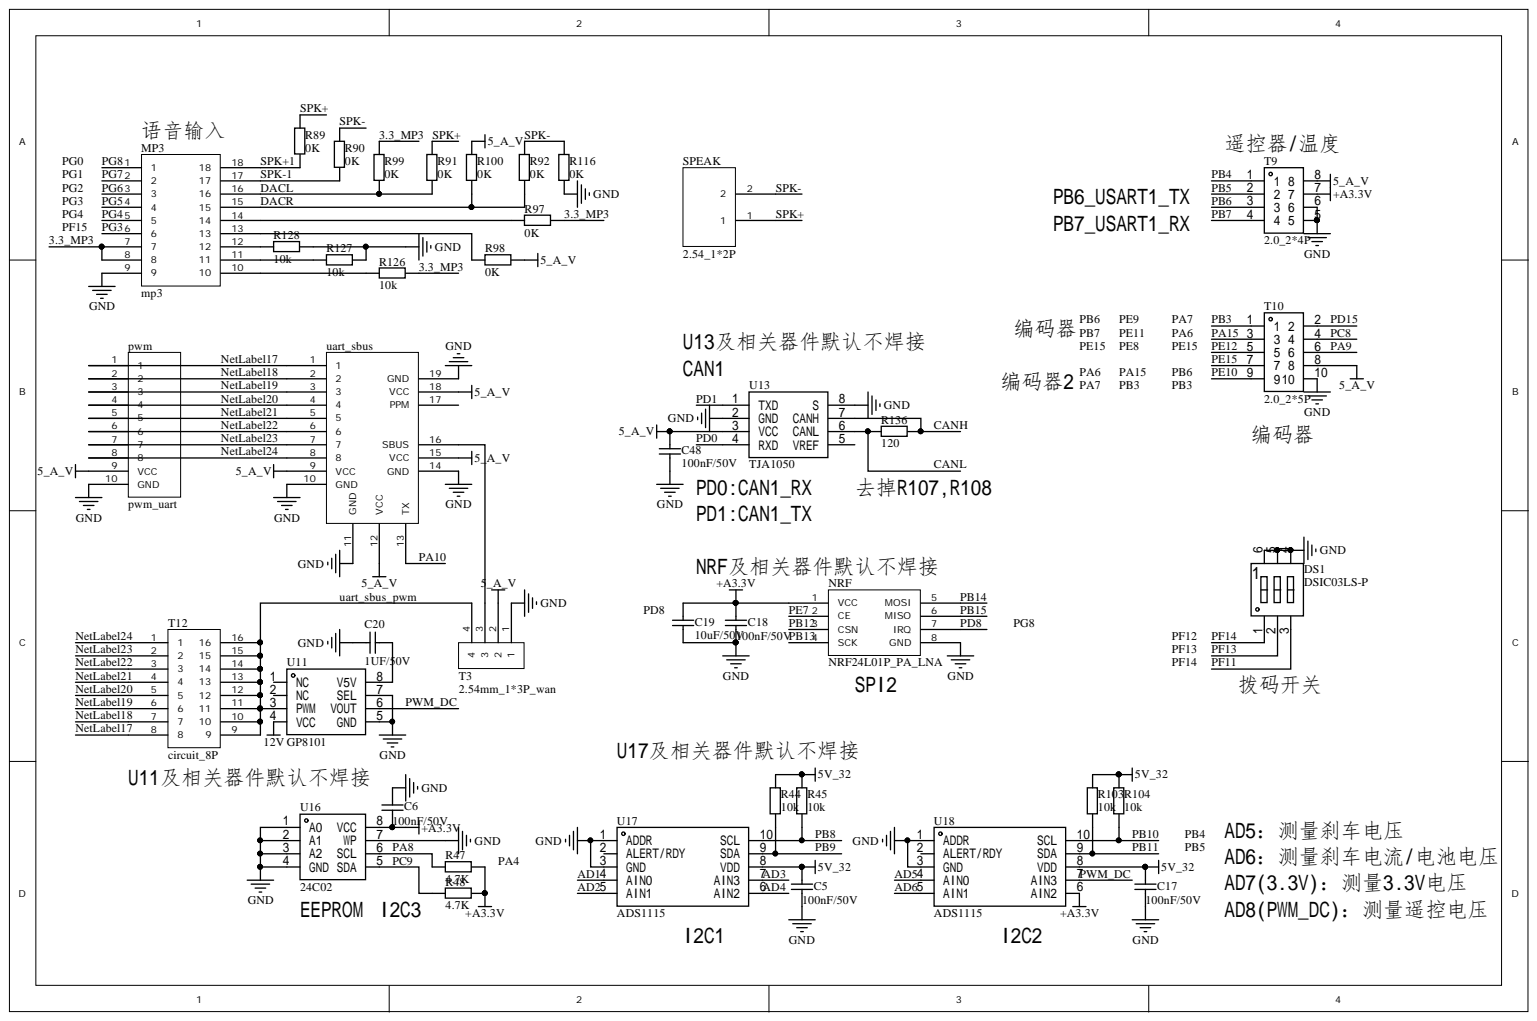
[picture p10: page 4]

4 4 | DACR
5 5 | | PB7

3 3 | NetLabel19 | 3 3
4 4 | NetLabel20 | 4 4
5 5 | NetLabel21 | 5 5

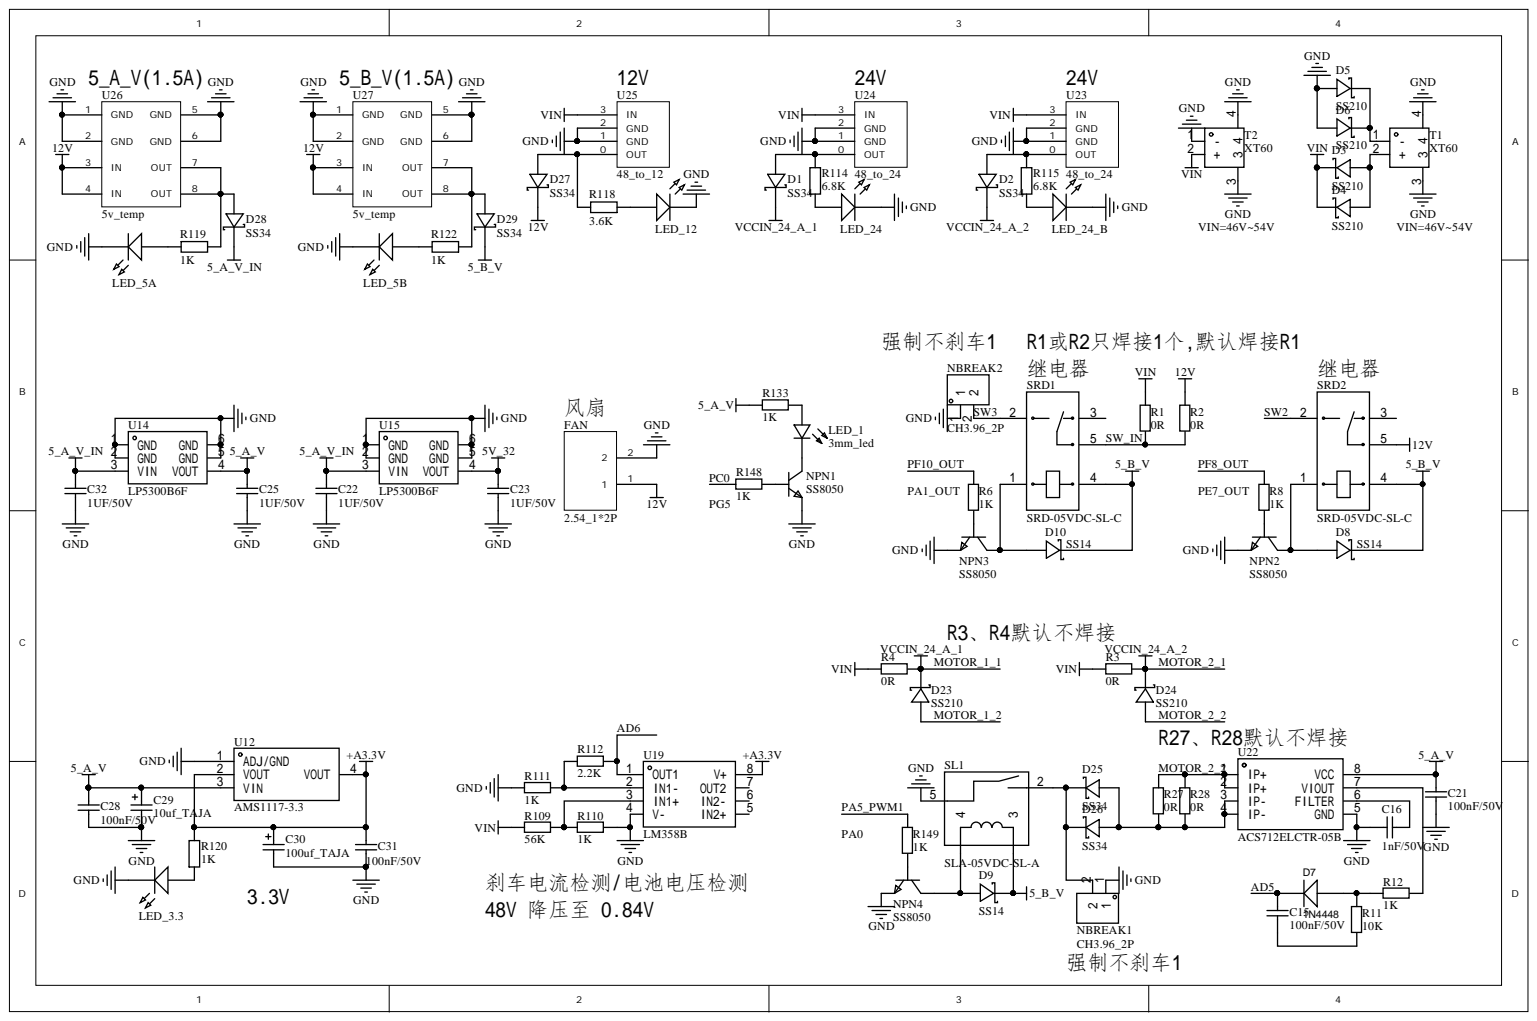
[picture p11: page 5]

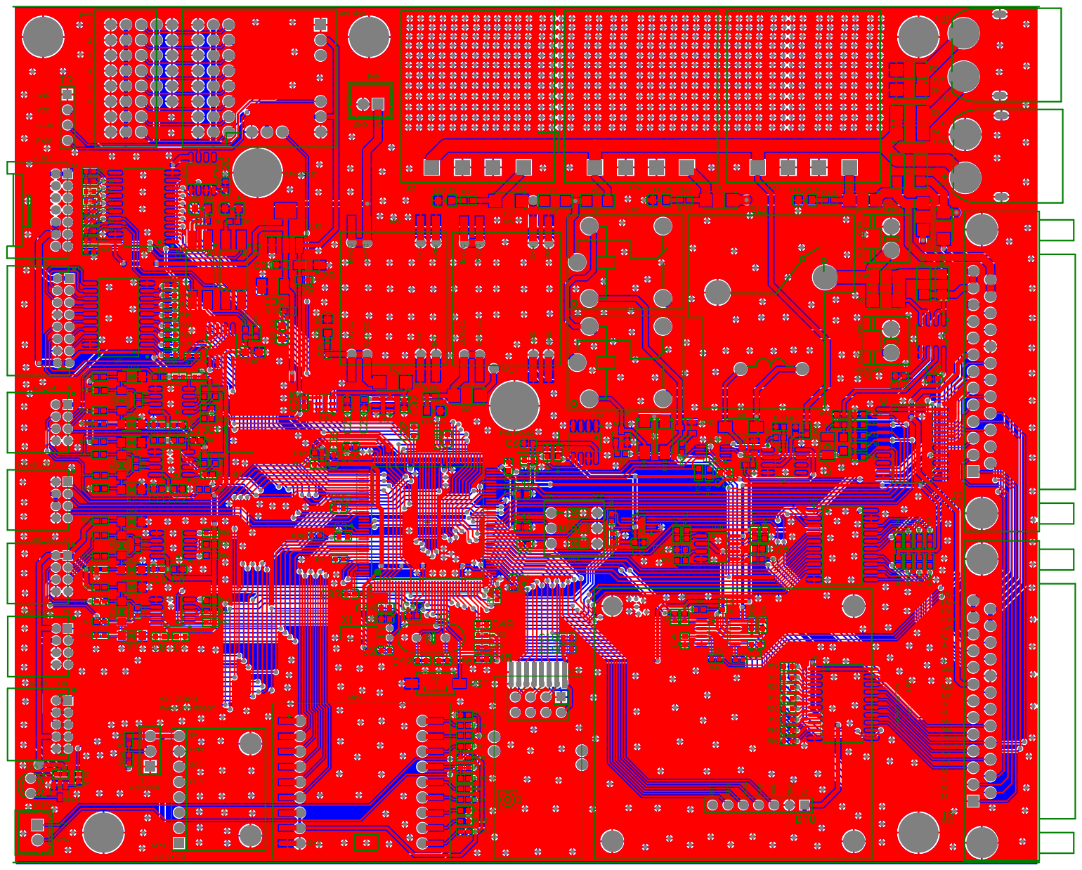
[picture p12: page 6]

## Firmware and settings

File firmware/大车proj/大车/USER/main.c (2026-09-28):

#include "sys.h"
#include "delay.h"
#include "usart.h"
#include "led.h"
#include "pwm.h"
#include "telecontrol.h"
//#include "lcd.h"
#include "retrofit.h"
/* Hw-24/Hw-25 (09-28): 本车四个行走轮的方向极性开关，逐轮独立、可单独回滚。
   现场定论(作者手调并保存): 只有**左前**一个轮需要翻 => LF=1, 其余 0。
   从动轮(无行走电机)是**左后** —— LR 这一位对实车无意义, 保留只为与调用点一一对应。
   中间那版"左前+右前都反 / 两反一正"的假设作废, 以本组实测值为准。
   相机装在除草刀上方、朝前 => 验收标准是"车朝刀侧/相机朝向走"。
   作用域: 翻在 main.c:564-573 的 pwm_veloc() 出口 => 纵向/横向/四轮转向/原地转
   一起变(接线极性是硬件属性, 本就不该分模式)。若某轮"纵向对、横向错",
   那不是极性问题, 而是 path_plan.c:548-555 轮序置换对本车不成立, 改法不同。
   勿改 car_control.c: 那里的 Out_Pwm/Roll_*_Dr 是上一代硬件遗留死代码
   (全工程无调用点, linker 已丢弃该 object)。
   搬去样机(2.15 m)后必须重测, 不得继承 (v1.0 4.1 执行方向逐台确认)。 */
#define DIR_SWAP_LF 1   /* 左前    实际上是纵向 */
#define DIR_SWAP_RF 0   /* 右前 */
#define DIR_SWAP_LR 1   /* 左后      本车从动，无行走电机  实际上是纵向*/
#define DIR_SWAP_RR 0   /* 右后 */
#include "path_plan.h"
#include "math.h"
#include "car_control.h"
//#include "can.h"
#include "adc.h"
#include "uart2.h"	
#include "uart5.h"	                
#include "uart4.h"	
#include "uart3.h"
#include "driver.h"
#include "iwdg.h"
#include "iic.h"
#include "exti.h"

// 角度传感器安装方向（上或下）
// 组别问题（左右一组，前后一组，必须按照顺序来，不再改变）

//车辆参数  轮轴 和轮距离
double B=1648.0; //车宽 mm
double L=3010.0;  //车长 mm
double B_Horizontal=3250.0; //车宽 mm
double L_Horizontal=1620.0;  //车长 mm


double veloc_limit_low =1.24;  //对应的满p波 尽量与实际相符  满p波与最高速的比例关系    这个是默认中速 还有高低速
double veloc_limit_middle =1.5;  //对应的满p波 尽量与实际相符  满p波与最高速的比例关系    这个是默认中速 还有高低速
double veloc_limit_high =1.74;  //对应的满p波 尽量与实际相符  满p波与最高速的比例关系    这个是默认中速 还有高低速

double veloc_actual=0.30;
double veloc_limit =1.24;  //对应的满p波 尽量与实际相符  满p波与最高速的比例关系    这个是最终值，不需要改变
double angle_limit=60.5/180.0*pi; ////控制角度限幅值，无需改变，自己运算  仅适用于双轮转向、斜行、相对转向模式  默认为（）


double angle_limit_single=65.5/180.0*pi; //单个车轮角度限幅值，可以更改


//传动比
double transmission_ratio_drive=5.5*2.0 ;// 行走电机传动比
double transmission_ratio_steer=50.0*8.0;//  伺服电机到车轮 50.0*5.5  快速车

double sensor_ratio=1.0;//  转向编码器以及电位计与转轴之间的传动比\

int ultrasonic_1=0,ultrasonic_2=0,ultrasonic_3=0,ultrasonic_4=0; //四路超声波的数值

//  转向限制标志位
u8 flag_steer_limit=0; // 是否有转向机械限位 0 没有 1有
double wheel_angle_limit=35.5/180.0*pi; //  如果有机械限位的话，限制是多少度
// 刹车电流检测对应的电压

// 角度传感器型号标志位
u8 flag_sensor=1; // 0是电位计 1是绝对值编码器
// 遥控器型号标志位
u8 flag_remote_control=1; // 0是航模遥控器 1是单手遥控器 2 是车模遥控器

// 转向方式标志位（绝对值转向还是增量式转向）
u8 flag_Steering_mode=1; // 0是绝对值式 1增量式

//增量式转向每次增的度数    
double angle_add=0.8*0.0175; //0.0175是1度，1.0中的 0不能省略   如果出现顿挫，加大这个数字

//转向电机默认转速设置
int steer_motor_speed=6000;

// 车辆模型。遥控器方式，通过拨码器进行设置
u8 flag_car_mode=0; // 0是四轮全能转向+航模 1是四轮有限位+航模 2是四轮有限位+车模 3是四轮有限位+单手遥控 4是双轮有限位+航模 5是双轮有限位+单手遥控 
 

// 是否进行避障号标志位  0不开启 1开启
u8 Obstacle_avoidance_flag=0,Obstacle_avoidance_flag_only=0; 
//电池电量低，报警清除标志位
u8 battery_voltage_flag_only=1;

//调整轴距标志位
u8 Adjusting_wheelbase=0; 

// 是否进行刹车保护标志位  0不开启 1开启
u8 Brake_protection_flag=0; 

float Brake_protection_value=2.3; //为单个刹车的电流

 
//所有的方向都是左正右负 角度为弧度单位  车速是米每秒  
int main(void)
{ 
	

  //double wheel_Angle_Init[4]={0,0,0,0};
  double wheel_Angle_Init[4]={3.1415926,3.1415926,3.1415926,3.1415926};		//左前3.99 右前2.50 左后 2.44 右后3.95;//四个轮子的初始值	，同步时两前轮相同两后轮相同  上位机要保存和修改的就是这个数
  double wheel_angle_limit=0.420;     //2.5度  定义车轮转向的机械极限角度 0.0175    25         
	
  extern u8 mp3_flag,mp3_flag_last,mp3_time,mp3_other;// 音乐播放类型、播放时间控制
	extern double Switch_direction;
  extern double control_flag[6];//0行驶还是停车，1前进还是后退，2转向方式，3角度值，4速度值，5作业机构是否起降  //*****************
	extern int sbus_channel[16];//解析后的通道数据            具体的各个位代表什么                           //**********************
	extern double veloc[4];	//每个车轮的转速                                                                   //*******************
	extern double angle[4];//每个车轮的转角                                                                      //***************
	extern u8 LOCK_FLAG; //遥控器锁	
	extern double battery_voltage,stop_voltage,base_voltage,control_voltage; //定义电池电压 刹车电压 基准电压  遥控器电压
	                     //************
	extern unsigned char regGroup[16]; //上位机接管数据
	extern u16 flag_sbus;
	int i=0,t,count,j,stop,stop_count,upload_count,only_start=0,stop_voltage_count=0;
	int shacheccr = 490;
	
	extern double AD_angle[4];//四个轮子的采集值  0左前，1右前，2左后，3右后                                         //**************
	double wheel_Angle_correct[4]={0,0,0,0};  // 0左前，1右前，2左后，3右后   车轮偏差的修正值

	double wheel_Angle_correct_run[4]={0,0,0,0};  // 0左前，1右前，2左后，3右后，运行中归正（回中间）
 	double Last_wheel_Angle_correct_run[4]={0,0,0,0};  // 0左前，1右前，2左后，3右后
	
	double  real_time_erro=0.0175*2;               //为1度    运行中大于这个角度，才修正
	extern int delay_usr;
   extern int  count_TIM4,Switch_direction_Horizontal_flag;
  
	extern int v0,v1,v2,v3;
//	double volt0,volt1,volt2,volt3;  ,
	
   extern	float tim3_low_time_ms; 
    extern float tim3_high_time_ms;
	
	int voltage_Progress_bar=0;
	int count_time=0;
	int flag_turn_break=0;
	int count_time_battery=0; //电池没电延时记录位
	
	NVIC_PriorityGroupConfig(NVIC_PriorityGroup_2);//设置系统中断优先级分组2
	delay_init(168);		//延时初始化 
	uart_init(115200);	//电脑串口初始化波特率为115200  调试串口 串口6
	uart2_init(9600);  //绝对值编码器
	USART1_SBUS_Init();  //遥控器
	uart5_init(115200);	//上位机（显示屏幕）                                      //*************上位机在这里
	uart4_init(19200);	//  转向伺服电机通信  （作业机构）
	
//	uart3_init(19200);
	TIM7_Init();
	


//  TIM1_PWM_Init(250,84-1);
	retrofit_init();		/* RETROFIT: weeding link/relays/stepper/wheel-capture *///84M/84=1Mhz 的计数频率计数到8400,频率为 1M/250=4Khz，行走电机	PWM输出  tim8pwm行走电机 
//			TIM_SetCompare1(TIM1,0);
//			TIM_SetCompare2(TIM1,0);
//			TIM_SetCompare3(TIM1,0);
//			TIM_SetCompare4(TIM1,0);
		
	
	LED_Init();		  		//初始化与LED连接的硬件接口
	replay_switch_Init();
	
	
	SW_3=1;  ///    总继电器打开，连电
	Position_light=1; //让示廓灯亮起来
	
//	PCout(3)=1;
//  PCout(4)=1; //上电默认为低速
	PFout(7)=0;
	PFout(6)=1;
	

	
	// 预留输出端口，无用
	PAout(11)=1;//上电默认推拉杆在中间
  PDout(3)=0;	
	
//	Encoder1_TIM4_init();
//	Encoder1_TIM1_init();

//	 TIM3_CH1_Cap_Init(0xEA60,8400-1);     //Tim3通道1通道2输入捕获（不只是通道1） 直流电机霍尔元器件高低电平时间与周期  间接测速	
		
	IIC_2_Init();                                                  //初始化车轮角度传感器（电位计）ADS115AD模块
	IIC_1_Init();			                                             //初始化刹车电流、电池电压检测ADS1115模块 
	
  EXTIX_Init();
	 
	TIM1_PWM_Init(250,84-1);//84M/84=1Mhz 的计数频率计数到8400,频率为 1M/250=4Khz，行走电机	PWM输出  tim8pwm行走电机 
		TIM_SetCompare1(TIM1,0);
		TIM_SetCompare2(TIM1,0);
		TIM_SetCompare3(TIM1,0);
		TIM_SetCompare4(TIM1,0);
	////////////////////////////////////上电初始化完成后开始一次AD采集////////////////////////////////////////////////////////////////////
    delay_ms(1000);                            //上电后等的那三秒   为了上电后电路更稳定 并且  方便后面的AD采集
		delay_ms(500); 
//			delay_ms(500); 
			for(j=0;j<2;j++)
		{
				if(flag_sensor==0)
				{
					ADC_angle_Check();//使用AD采集
				}
				if(flag_sensor==1)
				{
					get_angle_encode();;//使用编码器获取每个轮子当前AD值		
				}
		}

		wheel_Angle_correct[0]=(AD_angle[0]-wheel_Angle_Init[0])/sensor_ratio;  //初始车轮误差计算  0左前，1右前，2左后，3右后    //2.0的意义 2：1
		wheel_Angle_correct[1]=(AD_angle[1]-wheel_Angle_Init[1])/sensor_ratio;  //第一次上这个代码 先不让你修正车轮角度
		wheel_Angle_correct[2]=(AD_angle[2]-wheel_Angle_Init[2])/sensor_ratio;
		wheel_Angle_correct[3]=(AD_angle[3]-wheel_Angle_Init[3])/sensor_ratio;

//wheel_Angle_correct[0]=0; //加上传感器后记得去掉  //第二辆车还没加传感器 这个得赋0值
//wheel_Angle_correct[2]=0;
//wheel_Angle_correct[1]=0; //加上传感器后记得去掉
//wheel_Angle_correct[3]=0;


	////////////////////////////////////使能伺服电机///////////////////////////////////////////////////////////////////

		for(j=0;j<6;j++)
		{			
			mosbus_EN(j);  //每个电机mosbus使能
			delay_ms(10);	

	  }
		for(i=0;i<6;i++)
		{
			motor_EN(i);  //每个电机驱动器驱动使能
			delay_ms(10);
		}	
			for(j=0;j<6;j++)
		{			
					motor_speed(j,steer_motor_speed);  //每个电机设置旋转速度
				  delay_ms(10);	

	  }	
		
		
IWDG_Init(4,500); //与分频数prer为64,重载值rlr为500,溢出时间为1s	//时间计算(大概):Tout=((4*2^prer)*rlr)/32 (ms).		//初始化看门狗
		


		
		
///////////////////////////////////////////////////////////////////////////////////////////////////////////
////////////////////////////////////前面是启动时的初始化，成功初始化后开始while（1）/////////////////////////
///////////////////////////////////////////////////////////////////////////////////////////////////////////
///进行模式选择 车辆模型。遥控器方式，通过拨码器进行设置
if (PFin(3)==1)//说明刚开始就有遮挡，开启定时器
{
		TIM_Cmd(TIM7,ENABLE);
}
		
//	mp3_control(1);
//	delay_ms(5000);
//	
//  mp3_control(0);
//	delay_ms(5000);

//  mp3_control(2);
//	delay_ms(5000);
//		
//  mp3_control(0);
//	delay_ms(5000);
while(1)
{

	
	char tjcstr[48];	//定义一个字符串数组
	
			 count_time=count_time+1;
			
			if (count_time==10)   //每1s重新使能伺服电机，减少过载报警，过载后清掉
			{
				 count_time=0;
					
					for(i=1;i<5;i++)
				{
					motor_EN(i);  //每个电机驱动器驱动使能
					delay_ms(10);
				}	

			}
			
			
			
	
	if ( regGroup[0]==0 )//上位机未接管，正常遥控器控制
	{
	//	printf("上位机未接管");
	
							
							while(sbus_channel[4]<800 &&regGroup[0]==0 ) //说明遥控器居中或者断开(遥控器需要) ,大摇控器要读电压                   //入股遥控器没断  那就不会进入这个条件
							{
								path_plan();
								mp3_control(0);
							veloc[0]=0;
							veloc[1]=0;	
							veloc[2]=0;
							veloc[3]=0;
							angle[0]=0;
							angle[1]=0;
							angle[2]=0;
							angle[3]=0;	
							printf(" 遥控器未连接！\r\n");	
							snprintf(tjcstr, sizeof(tjcstr), "t6.txt=\"遥控器未连接！\"\xff\xff\xff" ); 
							 HMISends(tjcstr);	
								delay_ms(50);
							mp3_other=10;
							
							}
							
							

						//	
						//	
						if (only_start==0)   //提示请将油门拨到最低处
						{
							 mp3_other=0;
							
												if (sbus_channel[4]<1100)
											{
												only_start=1;
											}		
											
											if (sbus_channel[4]>1100)
													{
														while(only_start==0 && regGroup[0]==0)
														{
															path_plan();
															IWDG_Feed();
															printf(" 请将遥控器油门扳到最下方！\r\n");	
															
															snprintf(tjcstr, sizeof(tjcstr), "t6.txt=\"请将遥控器油门扳到最下方!\"\xff\xff\xff" ); 
															 HMISends(tjcstr);	
															//原延时50
																delay_ms(10);
															 mp3_other=11;
															
															if (sbus_channel[4]<1100)
															{
																only_start=1;
																 mp3_other=0;
															}
														}
																						

									}	
						}
							
							
							
							//select_flag_car_mode();
							IWDG_Feed();   //每次进行循环都先喂狗	

							path_plan();//sbus通讯传输遥控信息并解析计算,0左前，1右前，2左后，3右后                         //解析遥控器指令 并 执行 时必须做的

							/////////////////////////////////////////遥控器检测设置，如果上位机接管，这里要进行修改	

								if(sbus_channel[4]<1100) //说明遥控器在下方或者断开(遥控器需要) ,大摇控器要读电压                   //入股遥控器没断  那就不会进入这个条件
							{
							veloc[0]=0;
							veloc[1]=0;	
							veloc[2]=0;
							veloc[3]=0;

						//	printf(" 停车！%d \r\n",mp3_other);	
							//	SW_Stop=0;
								
							}
							else
							{
							if (!retrofit_estop_latched()) SW_Stop=1;
							}
	
	}
	
	if(regGroup[0]==1)	//上位机接管
	
	{
	IWDG_Feed();   //每次进行循环都先喂狗	

	path_plan();//sbus通讯传输遥控信息并解析计算,0左前，1右前，2左后，3右后                         //解析遥控器指令 并 执行 时必须做的
	
	}
	
/////////////////////////////////////////转向触碰开关设置	                                        //如果没碰到触碰开关就不会进入这个条件
	if (Touch_detection(flag_steer_limit) <9 ) // 返回9 说明没有任何触碰
	{
	veloc[0]=0;
	veloc[1]=0;	
	veloc[2]=0;
	veloc[3]=0;
//	angle[0]=0;
//	angle[1]=0;
//	angle[2]=0;
//	angle[3]=0;	
		
		//转向要立刻刹车，重新修改
		
	
	printf(" 转弯角度过大，触碰到行程开关！\r\n");			
	}


/////////////////////////////////////////刹车检测设置	                                     //如果刹车线没断 就不会进入这个条件
	if (Brake_protection_flag==1) //开启刹车电流保护
	{
			if(stop_voltage<=Brake_protection_value)	 //串联电流刹车线断了，电机刹车进行抱死  有速度还抱死 说明出问题了  不接刹车 2.539V  一个2.67  两个2.84		
			{		
				
	
				
				if(stop_voltage<=Brake_protection_value)
				{
						veloc[0]=0;	
						veloc[1]=0;	
						veloc[2]=0;
						veloc[3]=0;
						printf(" 停车，刹车故障请检查！\r\n");		
				}
			}
				else
				{	
				stop_voltage_count=0;

				
				
				}
	}

	
	////////////////////////////////////////////////////////////////////////////////////////////刹车设置	    如果有速度就不会进入这个条件

//if((veloc[0])==0&&veloc[1]==0&&veloc[2]==0&&veloc[3]==0) //没有速度，刹车	
	flag_turn_break=(( fabs(AD_angle[0]-wheel_Angle_Init[0])>=fabs(angle[0]-0.0175*5))&&( fabs(AD_angle[0]-wheel_Angle_Init[0])<=fabs(angle[0]+0.0175*5.0)))&&(( fabs(AD_angle[1]-wheel_Angle_Init[1])>=fabs(angle[1]-0.0175*5))&&( fabs(AD_angle[1]-wheel_Angle_Init[1])<=fabs(angle[1]+0.0175*5.0)))&&(( fabs(AD_angle[2]-wheel_Angle_Init[2])>=fabs(angle[2]-0.0175*5))&&( fabs(AD_angle[2]-wheel_Angle_Init[2])<=fabs(angle[2]+0.0175*5.0)))&&(( fabs(AD_angle[3]-wheel_Angle_Init[3])>=fabs(angle[3]-0.0175*5))&&( fabs(AD_angle[3]-wheel_Angle_Init[3])<=fabs(angle[3]+0.0175*5.0)));

	if((veloc[0])==0&&veloc[1]==0&&veloc[2]==0&&veloc[3]==0&&flag_turn_break) //没有速度，刹车	
  {
			if (Adjusting_wheelbase==1) //调整轴距
			{
			
			   if (!retrofit_estop_latched()) SW_Stop=1;
				 printf(" 轴距调整中！\r\n");	
			}
			if (Adjusting_wheelbase==0) //非调整轴距
			{				
					 if(stop_count++==20) //延时刹车  80ms一个控制周期，延时1s，需要16
								{
									if (!retrofit_estop_latched()) SW_Stop=0;
									 printf(" 刹车！\r\n");	
										stop_count=0;  //允许再次延时刹车	
								}
	
				}



			  }
/////////////////////////////////////////////////////////////  C超声波避障模块设置
		if(Obstacle_avoidance_flag==1)
		{
			
		//	printf(" 物 %d \r\n",delay_usr);	
			 if (delay_usr>1000)
				{
					
					
						
						veloc[0]=0;	
						veloc[1]=0;	
						veloc[2]=0;
						veloc[3]=0;
					
							printf(" 刹车有障碍物 %d \r\n",delay_usr);	
							snprintf(tjcstr, sizeof(tjcstr), "t8.txt=\"请注意有障碍物!\"\xff\xff\xff" ); 
								HMISends(tjcstr);	
							 mp3_other=8;	
					
					     if(Obstacle_avoidance_flag_only==0)
							{					
								 Obstacle_avoidance_flag_only=1;
							}

							
							
	
							
						
				}
				if (delay_usr<1000)
				{
					
					
				  	if(Obstacle_avoidance_flag_only==1)
							{
								mp3_other=0;
					      Obstacle_avoidance_flag_only=0;
							}
				
				}



		}			

//////////////////////////////////////////霍尔车速测量代码
		
	//		printf("%f %f %f \r\n",control_flag[4],tim3_low_time_ms,tim3_high_time_ms);
				

/////////////////////////////////////////运行代码     //运行代码赋相应的速度和转向角度时必须做的
				

		wheel_angle_limit_set(flag_steer_limit);  // 转角限幅后进行大小限制，如果没有限制，该代码没有作用
	
// 4左前，1右前，2左后，3右后
	  /* steering takeover (Fw-11): in AUTO the four angles are forced to
	     the calibrated straight position BEFORE send_angle runs - the
	     gate further below is too late, path_plan() rewrote angle[]. */
	  if (retrofit_mode() == MODE_AUTO) {
	      angle[0] = angle[1] = angle[2] = angle[3] = 0.0;
	  }
	  send_angle(4,-(angle[0]-wheel_Angle_correct[0]-Last_wheel_Angle_correct_run[1]-(retrofit_mode()==MODE_AUTO?0.0:Switch_direction)));   //角度控制  adress, angle    四个轮子 但是一个伺服电机控制两个  所以只控制两个就可以
	  delay_ms(12);
 
	  send_angle(1,(angle[1]+wheel_Angle_correct[1]-Last_wheel_Angle_correct_run[1]+(retrofit_mode()==MODE_AUTO?0.0:Switch_direction)));   //角度控制  adress, angle    四个轮子 但是一个伺服电机控制两个  所以只控制两个就可以
	  delay_ms(12);
	
	  send_angle(2,(angle[2]-wheel_Angle_correct[2]-Last_wheel_Angle_correct_run[1]+(retrofit_mode()==MODE_AUTO?0.0:Switch_direction)));   //角度控制  adress, angle    四个轮子 但是一个伺服电机控制两个  所以只控制两个就可以
	  delay_ms(12);
	
	  send_angle(3,-(angle[3]+wheel_Angle_correct[3]-Last_wheel_Angle_correct_run[1]-(retrofit_mode()==MODE_AUTO?0.0:Switch_direction)));   //角度控制  adress, angle    四个轮子 但是一个伺服电机控制两个  所以只控制两个就可以
	  delay_ms(12);
		
	//控制伺服电机
    
/* RETROFIT safety gate: AUTO uses slew-limited vision commands;
   ESTOP or retrofit fault forces zero. MANUAL falls through to the
   original SBUS path below, unchanged. */
	if (retrofit_mode() == MODE_AUTO) {
		float vl = 0.0f, vr = 0.0f;
		retrofit_get_wheel_cmd(&vl, &vr);
		veloc[0] = veloc[2] = vl;   /* left front/rear */
		veloc[1] = veloc[3] = vr;   /* right front/rear */
	} else if (retrofit_mode() == MODE_ESTOP) {
		veloc[0] = veloc[1] = veloc[2] = veloc[3] = 0.0;
	} else if (retrofit_mode() == MODE_MANUAL && !retrofit_sbus_ok()) {
		/* H2.3 (review 09-14): SBUS stale in MANUAL -> revoke stale RC
		   commands at the drive point. Recoverable, covers all 4 wheels
		   (unlike SW_Stop which only cuts MOTOR_1, see ledger Hw-2). */
		veloc[0] = veloc[1] = veloc[2] = veloc[3] = 0.0;
	}
//左前
			pwm_veloc(0, DIR_SWAP_LF ? -veloc[0] : veloc[0]);  //速度控制
			
//左后	
			pwm_veloc(2, DIR_SWAP_LR ? -veloc[2] : veloc[2]);   //速度控制

//右前	
			pwm_veloc(1, DIR_SWAP_RF ? -veloc[1] : veloc[1]);	//速度控制

////右后	
			pwm_veloc(3, DIR_SWAP_RR ? -veloc[3] : veloc[3]);   //速度控制
	 


//printf(" ch0 %d ch1 %d ch2 %d  ch3 %d ch4 %d ch5 %d ch6 %d ch7 %d ch8 %d ch9 %d \r\n",regGroup[0],regGroup[1],regGroup[2],regGroup[3],regGroup[4],regGroup[5],regGroup[6],regGroup[7],regGroup[8],regGroup[9] );	
//printf("\n");
//printf("  ch0 %d ch1 %d ch2 %d  ch3 %d ch4 %d ch5 %d ch6 %d ch7 %d ch8 %d ch9 %d \r\n",sbus_channel[0],sbus_channel[1],sbus_channel[2],sbus_channel[3],sbus_channel[4],sbus_channel[5],sbus_channel[6],sbus_channel[7],sbus_channel[8],sbus_channel[9] );	
//printf("\n");
//printf(" 停车 %f  方向 %f 转向  %f 角度 %f  速度 %f   mp3_flag %d mp3_flag_last %d mp3_time %d Switch_direction %f \r\n",control_flag[0],control_flag[1],control_flag[2],control_flag[3],control_flag[4], mp3_flag,mp3_flag_last,mp3_time,Switch_direction );			
////regGroup																																												//0行驶还是停车，1前进还是后退，2转向方式，3角度值，4速度值，5作业机构是否起降		
//printf("\n");
//printf("角度: 左前%f  左后%f 右前%f 右后%f 速度：左前%f 左后%f  右前%f 右后%f 电池%f 刹车%f 基准%f 遥控器%f 转向 %f  %d\r\n",angle[0],angle[2],angle[1],angle[3],veloc[0],veloc[2],veloc[1],veloc[3],battery_voltage,stop_voltage,base_voltage,control_voltage,control_flag[2],flag_Steering_mode);
//printf("\n");
printf("总角度 %.3f  总速度 %.3f 角度: 左前%.3f  左后%.3f 右前%.3f 右后%.3f 速度：左前%.3f 左后%.3f  右前%.3f 右后%.3f 电池%.3f 刹车%.3f 转向 %.3f 前进%.3f 横向 %d\r\n",control_flag[3]/3.14*180.0,control_flag[4],angle[0]/3.14*180.0,angle[2]/3.14*180.0,angle[1]/3.14*180.0,angle[3]/3.14*180.0,veloc[0],veloc[2],veloc[1],veloc[3],battery_voltage,stop_voltage,control_flag[2],control_flag[1],Switch_direction_Horizontal_flag);


//					AD_all(2,100);//获取每个轮子当前AD值	
//get_angle_encode();;//使用编码器获取每个轮子当前AD值					
//printf("初始AD角度: 左前%f 左后%f  右前%f 右后% f \r\n",AD_angle[0],AD_angle[2],AD_angle[1],AD_angle[3]);//四个轮子的采集值






 		LED0=!LED0;
		LED1=!LED1;
		if (count++==20)
		{		
			count=0;
    //ADC_angle_Check();//使用AD采集		
   //  get_angle_encode();;//使用编码器获取每个轮子当前AD值					
		ADC_electric_Check();  // 每2秒检测一下电池电压、刹车电流等信息

//		Position_light=!Position_light;  ///    示廓灯
		
		if(battery_voltage<44  && count_time_battery++>60*10*30)//如果电压低于44断开，保护电池,且超过30分钟
		{
			SW_3=0;  ///    总继电器断开，断电
			//SW_3=1;
		
		}
		else
		{
		count_time_battery=0;
		
		}
			
		//向上位机传输信息
		//电压
		snprintf(tjcstr, sizeof(tjcstr), "t1.txt=\"%d.%d V\"\xff\xff\xff", (int)battery_voltage,(int)((battery_voltage-(int)battery_voltage)*10)); 
    HMISends(tjcstr);	

    voltage_Progress_bar=(int)((battery_voltage-44.0)/(56.0-44.0)*100);
		if (voltage_Progress_bar>=20)
			{
			snprintf(tjcstr, sizeof(tjcstr), "j1.pco=2024\xff\xff\xff" ); //绿色
			HMISends(tjcstr);	
			snprintf(tjcstr, sizeof(tjcstr), "j1.val=%d\xff\xff\xff",voltage_Progress_bar );  
			HMISends(tjcstr);
			snprintf(tjcstr, sizeof(tjcstr), "t8.txt=\"正常运行!\"\xff\xff\xff" ); 
			HMISends(tjcstr);			
			snprintf(tjcstr, sizeof(tjcstr), "t6.txt=\"遥控器连接成功!\"\xff\xff\xff" );   
			HMISends(tjcstr);		
			if( battery_voltage_flag_only==1)
			{mp3_other=0;	 //让其一直响吧
			 battery_voltage_flag_only=0;
				
				
				
		   }
				
			}
		if (voltage_Progress_bar<10)   //没电了
			{
			snprintf(tjcstr, sizeof(tjcstr), "j1.pco=63488\xff\xff\xff" ); //红色
			HMISends(tjcstr);		
			snprintf(tjcstr, sizeof(tjcstr), "j1.val=%d\xff\xff\xff",voltage_Progress_bar ); 
			HMISends(tjcstr);			
			snprintf(tjcstr, sizeof(tjcstr), "t8.txt=\"请充电!\"\xff\xff\xff" ); 
			HMISends(tjcstr);	
      //mp3_other=9;	 //让其一直响吧
				
				printf("没电了 %d \r\n",mp3_other);	
				
			if( battery_voltage_flag_only==0)
			{
			 battery_voltage_flag_only=1;
		   }
			}			
		//速度信息

		snprintf(tjcstr, sizeof(tjcstr), "t7.txt=\"%d.%dm/s\"\xff\xff\xff", (int)control_flag[4],(int)((control_flag[4]-(int)control_flag[4])*10));  
		HMISends(tjcstr);	
		
		snprintf(tjcstr, sizeof(tjcstr), "j0.val=%d\xff\xff\xff",(int)((control_flag[4]-0.0)/(veloc_limit-0.0)*100) );  
		HMISends(tjcstr);
		// 转向模式
			
			if(control_flag[2]==1)
			{
			snprintf(tjcstr, sizeof(tjcstr), "t4.txt=\"两轮转向!\"\xff\xff\xff" ); 
			HMISends(tjcstr);	
			}
			if(control_flag[2]==2)
			{
			snprintf(tjcstr, sizeof(tjcstr), "t4.txt=\"四轮转向!\"\xff\xff\xff" ); 
			HMISends(tjcstr);	
			}
			if(control_flag[2]==3)
			{
			snprintf(tjcstr, sizeof(tjcstr), "t4.txt=\"斜行转向!\"\xff\xff\xff" ); 
			HMISends(tjcstr);	
			}
			if(control_flag[2]==4)
			{
			snprintf(tjcstr, sizeof(tjcstr), "t4.txt=\"原地转向!\"\xff\xff\xff" ); 
			HMISends(tjcstr);	
			}

			
	
			
		}
		
		
}



}

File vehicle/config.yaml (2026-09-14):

# vehicle side config (RDK X5) — fill in per deployment  (R3, 2026-09-14)
serial_dev: /dev/ttyS1     # 40-pin UART1 (Pin8/10) to STM32 USART6, 3.3V direct
baud: 115200
udp_port: 9000             # bridge listens here for PC control frames
pc_ip: 192.168.127.100     # PC running perception/control (X5 eth0 is .10)
pc_port: 9100              # bridge sends MCU status frames here
stream:
  # TCP multipart MJPEG: X5 is the SERVER (tcpserversink); PC connects OUT.
  # No pc_ip here — see vehicle/stream_pi.py + common/mjpeg.py.
  port: 5000
  width: 1280
  height: 720
  fps: 30
watchdog_ms: 500           # must match firmware LINK_TIMEOUT_MS
# allowed_sources: [192.168.127.100]   # optional: UDP source IPs
#                           default = pc_ip above; other LAN hosts are dropped

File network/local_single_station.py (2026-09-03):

"""Real-time peony-row navigation system -- onboard deployment.

Pipeline:
  1. Multi-threaded camera capture (1920x1080 raw -> 960x720 crop)
  2. DeepLabV3+ inference (MobileNetV2, 2-class: bg / peony-wall)
  3. IPM projection to bird's-eye view
  4. Wall-building morphology + noise filtering
  5. Dual-wall least-squares centerline fitting
  6. Visualization overlay with FPS / lateral error / heading

Press ESC to exit.
"""

import os
import sys
import cv2
import torch
import math
import time
import threading
import numpy as np

# Add project root to path so imports work from any working directory
_PROJ_ROOT = os.path.abspath(os.path.join(os.path.dirname(__file__), ".."))
for _p in (_PROJ_ROOT, os.path.join(_PROJ_ROOT, 'tools')):
    if _p not in sys.path:
        sys.path.insert(0, _p)

from network.modeling import deeplabv3plus_mobilenet
from morph_process import peony_postprocess
from network.camera_calib import undistort, apply_ipm, ipm_mask_to_physical, IPM_SCALE_X

# ===================== Deployment parameters =====================
DEVICE = torch.device("cuda" if torch.cuda.is_available() else "cpu")
WEIGHT_PATH = os.path.join(_PROJ_ROOT, "model_data", "weights", "best_model.pth")

# Model fixed resolution
WIDTH, HEIGHT = 960, 720
MID_X = WIDTH // 2

# Preprocessing normalization (on GPU)
MEAN = torch.tensor([0.485, 0.456, 0.406], device=DEVICE).view(1, 3, 1, 1)
STD  = torch.tensor([0.229, 0.224, 0.225], device=DEVICE).view(1, 3, 1, 1)

# Camera config -- adjust for your actual setup
CAMERA_INDEX = 0
TOP_CUT, BOTTOM_CUT = 180, 180
LEFT_CUT, RIGHT_CUT = 480, 480

# Safety
LATERAL_SAFETY_LIMIT_M = 0.15   # 15 cm: trigger E-STOP if exceeded

# Visualization colors (BGR)
COLOR_LEFT_WALL  = (255, 100, 100)   # blue-ish
COLOR_RIGHT_WALL = (100, 255, 100)   # green-ish
COLOR_CENTERLINE = (0, 255, 255)     # yellow
COLOR_INFO       = (0, 255, 0)


# ===================== Multi-threaded camera stream =====================
class CameraStreamThread:
    def __init__(self, src=0):
        self.cap = cv2.VideoCapture(src, cv2.CAP_DSHOW)
        self.cap.set(cv2.CAP_PROP_FOURCC, cv2.VideoWriter_fourcc(*'MJPG'))
        self.cap.set(cv2.CAP_PROP_FRAME_WIDTH,  1920)
        self.cap.set(cv2.CAP_PROP_FRAME_HEIGHT, 1080)
        self.grabbed, self.frame = self.cap.read()
        self.started = False
        self.read_lock = threading.Lock()

    def start(self):
        self.started = True
        self.thread = threading.Thread(target=self.update, daemon=True)
        self.thread.start()
        return self

    def update(self):
        while self.started:
            grabbed, frame = self.cap.read()
            if grabbed:
                with self.read_lock:
                    self.grabbed, self.frame = grabbed, frame

    def read(self):
        with self.read_lock:
            return self.grabbed, self.frame.copy() if self.frame is not None else (False, None)

    def release(self):
        self.started = False
        if hasattr(self, 'thread'):
            self.thread.join(timeout=1.0)
        self.cap.release()


# ===================== Model loader =====================
def load_model():
    if not os.path.exists(WEIGHT_PATH):
        raise FileNotFoundError(f"Weight file not found: {WEIGHT_PATH}")
    model = deeplabv3plus_mobilenet(num_classes=2, output_stride=16,
                                     pretrained_backbone=False)
    model.load_state_dict(torch.load(WEIGHT_PATH, map_location=DEVICE))
    model.to(DEVICE).eval()
    return model


# ===================== Visualization helpers =====================
def draw_walls_overlay(display, left_wall, right_wall, alpha=0.35):
    """Semi-transparent overlay of wall masks onto the display image."""
    overlay = np.zeros_like(display)
    overlay[left_wall  > 0] = COLOR_LEFT_WALL
    overlay[right_wall > 0] = COLOR_RIGHT_WALL
    return cv2.addWeighted(display, 1.0 - alpha, overlay, alpha, 0)


def draw_centerline(display, nav_result):
    """Draw the centerline on the display image."""
    if nav_result["center_x"] is None:
        return
    cx = int(nav_result["center_x"])
    cv2.line(display, (cx, HEIGHT), (cx, 0), COLOR_CENTERLINE, 2)
    # Also draw the midline reference
    cv2.line(display, (MID_X, HEIGHT), (MID_X, 0), (128, 128, 128), 1)


def draw_left_right_lines(display, nav_result, lookahead_y=540):
    """Draw the fitted wall lines."""
    h = display.shape[0]
    for key, color in [("left_x", COLOR_LEFT_WALL), ("right_x", COLOR_RIGHT_WALL)]:
        if nav_result[key] is not None and nav_result.get(key.replace("_x", "_slope")) is not None:
            slope = nav_result[key.replace("_x", "_slope")]
            intercept = nav_result[key] - slope * lookahead_y
            x0 = int(slope * 0 + intercept)
            x1 = int(slope * h + intercept)
            cv2.line(display, (x0, 0), (x1, h), color, 1)
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

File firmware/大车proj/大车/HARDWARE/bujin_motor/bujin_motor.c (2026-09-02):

#include "sys.h"
#include "delay.h"
#include "usart.h"
#include "math.h"
#include "stdint.h"
#include "bujin_motor.h" 


#define F2TIME_PARA				12000000   									//将频率值转换为定时器寄存器值得转换参数
#define STEP_PARA					10	   											//任意时刻转动步数修正因子
#define STEP_AA						31       										//加加速阶段，离散化点数
#define STEP_UA						31			  									//匀加速阶段，离散化点数
#define STEP_RA						31													//减加速阶段，离散化点数

#define STEP_SPTA					20													//SPTA最大速度等级
#define MAXSPEED_SPTA			80000												//SPTA最大速度
#define ACCSPEED_SPTA			150000											//SPTA加速度


//*正常S型曲线参数生成的表格*/
uint16_t Motor1TimeTable[2*(STEP_AA+STEP_UA+STEP_RA)+1] = {0};
uint16_t Motor1StepTable[2*(STEP_AA+STEP_UA+STEP_RA)+1] = { 0};
uint16_t Motor2TimeTable[2*(STEP_AA+STEP_UA+STEP_RA)+1] = { 0};
uint16_t Motor2StepTable[2*(STEP_AA+STEP_UA+STEP_RA)+1] = { 0};
uint16_t Motor3TimeTable[2*(STEP_AA+STEP_UA+STEP_RA)+1] = { 0};
uint16_t Motor3StepTable[2*(STEP_AA+STEP_UA+STEP_RA)+1] = { 0};	

//*将参数降为2/3 S型曲线参数生成的表格*/
uint16_t Motor1_23TimeTable[2*(STEP_AA+STEP_UA+STEP_RA)+1] = { 0};
uint16_t Motor1_23StepTable[2*(STEP_AA+STEP_UA+STEP_RA)+1] = { 0};
uint16_t Motor2_23TimeTable[2*(STEP_AA+STEP_UA+STEP_RA)+1] = { 0};
uint16_t Motor2_23StepTable[2*(STEP_AA+STEP_UA+STEP_RA)+1] = { 0};
uint16_t Motor3_23TimeTable[2*(STEP_AA+STEP_UA+STEP_RA)+1] = { 0};
uint16_t Motor3_23StepTable[2*(STEP_AA+STEP_UA+STEP_RA)+1] = { 0};	
//*将参数降为1/3 S型曲线参数生成的表格*/
uint16_t Motor1_13TimeTable[2*(STEP_AA+STEP_UA+STEP_RA)+1] = { 0};
uint16_t Motor1_13StepTable[2*(STEP_AA+STEP_UA+STEP_RA)+1] = { 0};
uint16_t Motor2_13TimeTable[2*(STEP_AA+STEP_UA+STEP_RA)+1] = { 0};
uint16_t Motor2_13StepTable[2*(STEP_AA+STEP_UA+STEP_RA)+1] = { 0};
uint16_t Motor3_13TimeTable[2*(STEP_AA+STEP_UA+STEP_RA)+1] = { 0};
uint16_t Motor3_13StepTable[2*(STEP_AA+STEP_UA+STEP_RA)+1] = { 0};	


MOTOR_CONTROL_S motor1;	     	 
MOTOR_CONTROL_S motor2;	     	 
MOTOR_CONTROL_S motor3;	      
MOTOR_CONTROL_SPTA motor4;



//PWM输出初始化
//arr：自动重装值
//psc：时钟预分频数
void Initial_PWM_Motor1(void) //TIM2
{		 					 
   //此部分需手动修改IO口设置
   GPIO_InitTypeDef GPIO_InitStructure;
   TIM_TimeBaseInitTypeDef  TIM_TimeBaseStructure;
   TIM_OCInitTypeDef  TIM_OCInitStructure;
   NVIC_InitTypeDef NVIC_InitStructure;
	
	
   RCC_APB1PeriphClockCmd(RCC_APB1Periph_TIM2,ENABLE);  	//TIM14时钟使能    
   RCC_AHB1PeriphClockCmd(RCC_AHB1Periph_GPIOA, ENABLE); 	//使能PORTF时钟	

   GPIO_PinAFConfig(GPIOA,GPIO_PinSource15,GPIO_AF_TIM2); //GPIOF9复用为定时器14

   GPIO_InitStructure.GPIO_Pin = GPIO_Pin_15;           //GPIOF9
   GPIO_InitStructure.GPIO_Mode = GPIO_Mode_AF;        //复用功能
   GPIO_InitStructure.GPIO_Speed = GPIO_Speed_100MHz;	//速度100MHz
   GPIO_InitStructure.GPIO_OType = GPIO_OType_PP;      //推挽复用输出
   GPIO_InitStructure.GPIO_PuPd = GPIO_PuPd_UP;        //上拉
   GPIO_Init(GPIOA,&GPIO_InitStructure);              //初始化PF9

	
		TIM_DeInit(TIM2);
		 //中断NVIC设置：允许中断，设置优先级
		NVIC_InitStructure.NVIC_IRQChannel = TIM2_IRQn;     
		NVIC_InitStructure.NVIC_IRQChannelPreemptionPriority =PWM1_PreemptionPriority;   
		NVIC_InitStructure.NVIC_IRQChannelSubPriority = PWM1_SubPriority;          
		NVIC_InitStructure.NVIC_IRQChannelCmd = ENABLE;             
		NVIC_Init(&NVIC_InitStructure);
		
	
	
   TIM_TimeBaseStructure.TIM_Prescaler=5;  //定时器分频710000
   TIM_TimeBaseStructure.TIM_CounterMode=TIM_CounterMode_Up; //向上计数模式
   TIM_TimeBaseStructure.TIM_Period=1000;   //自动重装载值
   TIM_TimeBaseStructure.TIM_ClockDivision=TIM_CKD_DIV1; 
   TIM_TimeBaseStructure.TIM_RepetitionCounter = 0;

   TIM_TimeBaseInit(TIM2,&TIM_TimeBaseStructure);//初始化定时器14

   //初始化TIM14 Channel1 PWM模式	 
   TIM_OCInitStructure.TIM_OCMode = TIM_OCMode_PWM2; //选择定时器模式:TIM脉冲宽度调制模式2
   TIM_OCInitStructure.TIM_OutputState = TIM_OutputState_Enable; //比较输出使能
	 TIM_OCInitStructure.TIM_OutputNState = TIM_OutputNState_Enable; //互补信号输出到对应的输出引脚
   TIM_OCInitStructure.TIM_OCPolarity = TIM_OCPolarity_Low; //输出极性:TIM输出比较极性低
   TIM_OCInitStructure.TIM_OCNPolarity = TIM_OCNPolarity_High;
   TIM_OCInitStructure.TIM_OCIdleState = TIM_OCIdleState_Reset;
   TIM_OCInitStructure.TIM_OCNIdleState = TIM_OCIdleState_Reset;
   TIM_OCInitStructure.TIM_Pulse = 50; 
   TIM_OC1Init(TIM2, &TIM_OCInitStructure);  //根据T指定的参数初始化外设TIM1 4OC1
   TIM_OC1PreloadConfig(TIM2, TIM_OCPreload_Enable);  //使能TIM14在CCR1上的预装载寄存器
  
   TIM_ARRPreloadConfig(TIM2,ENABLE);//ARPE使能 


	//清中断，以免一启用中断后立即产生中断
	TIM_ClearFlag(TIM2, TIM_FLAG_Update);
	//使能TIM1中断源
	TIM_ITConfig(TIM2, TIM_IT_Update, ENABLE);

   TIM_Cmd(TIM2, DISABLE);  //使能TIM2
	 
	// 	TIM_CtrlPWMOutputs(TIM2,ENABLE); //使能PWM输出
	 
}
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

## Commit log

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2026-09-02 feat: perception wrapper + offline replay (W1)
    - pc/perception.py: lazy calib (fixes hardcoded-path crash), undistort fix
    (remap at native res; original camera_calib resized first => quarter-frame bug),
    DeepLabV3+ infer -> IPM -> dual-wall, far/near lookahead split
    - pc/replay.py: video/dir replay, CSV log, overlay rendering
    - verified: training-domain test image status=dual, chain correct;
    avi frames show domain gap (fg=0.55 oversegmentation) -> autumn fine-tune planned
    - docs/refs/参考资料调研.md: thesis + GitHub research
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2026-09-02 feat: firmware retrofit C code, control layer, vehicle bridge (W1-W2 code complete)
    - firmware/: protocol.c/h (byte-stream parser, CRC16), retrofit.c/h (UART6 link,
    dual-command-source AUTO/MANUAL, knife interlock, 500ms watchdog, TIM4 stepper,
    TIM3 wheel-speed capture, 0x10 status@20Hz) + integration guide (needs Keil build)
    - pc/control.py: MiddleToolPID (conditional anti-windup), LatencyCompensator (p50/p95),
    DifferentialDrive, LatErrorRate
    - pc/state_machine.py: ESTOP-latched 4-state safety machine
    - vehicle/: bridge.py (UDP<->UART + watchdog logic, tested), stream_pi.py, config.yaml
    - common/protocol.py: extract_one stream splitter
    - tests: 28/28 passed (4 real test bugs fixed dur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
    [config.yaml, protocol.py, retrofit.c]
2026-09-02 feat: firmware integrated & Keil build PASSING (0 errors, Code=44KB)
    - full Keil project copy at firmware/大车proj with RETROFIT group wired
    - main.c: retrofit_init(); retrofit.c: TIM6 1ms tick + sbus notify + wheel cmd getter
    - usart.c: legacy USART6 debug handler disabled (link owned by protocol)
    - telecontrol.c: SBUS heartbeat hook; car_control.c: Out_Pwm AUTO injection
    - uvprojx: RETROFIT group + include path; stale zip OBJ caused false link errors (cleaned)
    - hex generated; bench calib items remain (stepper mm, wheel pulse, AD5 current)
    [MotorStart.c, adc.c, bujin_motor.c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]
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2026-09-02 feat: pc/main.py — full control loop (replay/live), GUI overlay, ESTOP interlock verified
    - FrameSource unified over video/dir/RTP; state machine drives NAV/TOOL/HEARTBEAT
    - lateral |>5cm| -> ESTOP (verified live in smoke); vision-loss 2s -> LIFT
    - GUI: overlay + HUD + key controls (a/m/e/r/q); CSV run log
    - smoke: avi frames -> MANUAL+heartbeat OK; training-domain frame -> dual, estop on
    exaggerated placeholder-IPM lateral (safety chain correct)
    [run_log.csv]
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2026-09-02 docs: schematic PDF cross-check report
    - CPU silkscreen confirmed STM32F407ZGT6 (PDF is newer rev than SchDoc)
    - PA5/SL1 = brake relay (energized=released, fail-safe); NBREAK2 = main relay
    external break point (estop button candidate)
    - U7 485 bus only exits to T6 connector -> USART6 free if T6 unpopulated
    - B6 field checklist reduced 5 -> 3 items
2026-09-02 docs: merge agent schematic verification (SL1 = MOTOR_1 24V power relay, DS1=PF12/14/13); correct B6
2026-09-02 docs: chapter-4 theory materials (skid-steer error model, latency feed-forward derivation, IPM error analysis) + thesis defense Q&A
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2026-09-03 feat: IPM calibration tool (D4) + firmware F1 slew limiter & F2 IWDG, Keil 0 errors
    - pc/calib_ipm.py: grab/pick/solve, DLT homography, reprojection self-test 5.9mm @0.8px noise
    - retrofit.c: slew-rate limiter 0.2 m/s^2 on AUTO wheel cmds (bumpless transfer), IWDG 1.6s
    fed @200ms (reset -> MANUAL safe state); Code=44408, 0 errors
    [retrofit.c]
2026-09-03 feat: F5 adaptive dual-wall centerline with offline ablation validation
    - row-voting trimmed LSQ (fixes pixel-density bias: dense blob vs sparse wall)
    - gated weighting: active only when a wall inlier ratio <0.5, bounded +-0.25
    - ablation results: real masks 0.1px deviation (strict no-op); synthetic dense
    occlusion 25.5->0.5px (hard case), 2.1->1.6px (random-slope suite); 30/30 tests
    - docs: slew-rate calibration added to B4; weed-density grading standard added
    to collection checklist; BiSeNet paper comparison added to theory materials
2026-09-04 fix(bridge): reassemble serial stream across read boundaries — cache extract_one remainder instead of dropping it
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2026-09-04 fix(P0): wire retrofit safety gate into real drive path; explicit ESTOP wire frame; dedup IWDG
    Review findings fixed (all verified in code before fixing):
    - P0-1: gate was patched into car_control.c which is NOT in the Keil build;
    real drive is main.c pwm_veloc. Gate now sits at the pwm_veloc site:
    AUTO -> retrofit slew-limited wheel cmds, ESTOP -> all four zero,
    MANUAL -> original SBUS path untouched. Missing retrofit_mode() body added.
    - P0-2: pc/main.py now sends TYPE_ESTOP once on transition into ESTOP/LIFT
    (heartbeat alone never implied safety; MCU latches on this frame).
    - P0-3: removed duplicate retrofit IWDG (same peripheral); board IWDG in
    main.c retained, covers retrofit/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
    [main.c, retrofit.c]
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2026-09-05 docs: E2.2 switch Pi4B -> RDK X5 10TOPS (Pi4B price hike inverts economics; ZCode owns adaptation)
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2026-09-05 docs: user clarifies actuator semantics (3 rods = 3 row blades passive depth), T5 relay purpose unknown (new B6 item), wheel-motor control same as firmware (Hw-10 resolved)
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2026-09-05 docs: steering AUTO-gap (Fw-11: angle[] not seized in AUTO), straight-line drift diagnosis (Fw-12), middle-tool adjust absent (Hw-12, recommend defer), servo set = steering (Hw-13)
2026-09-05 docs: cancel TB6600 purchase (E2.3) — middle-tool slide is servo+screw (installed, unwired, Hw-12 resolved, Modbus-bus option recommended); vehicle geometry dims to be measured (Hw-14, user's actual 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
2026-09-05 docs: correct Hw-13 — steering servo already installed & wired (links are reference for on-car parts, not new purchases); register-map check only applies to unwired slide servo
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2026-09-08 docs: third external review triage — 8/8 P0 confirmed (AUTO unreachable, normalization 255x, ESTOP never wired, bridge boot lockout, printf pollution, replay sends, boot knives-down, paper kinematics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
2026-09-08 docs: AGENTS.md status rewritten post third review — AUTO/wiring/train bans, confirmed hardware facts, fix batches
2026-09-08 fix(P0 batch1): /255 normalization (P0-3), ESTOP wire on vision-loss & key-E (P0-4), bridge cold-start no-inject (P0-5), replay send guard (P0-8), tool_offset None guard (P1-3), train paths workspace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
2026-09-08 fix(firmware P0-2/P0-6): NAV implies AUTO + HEARTBEAT releases to MANUAL (AUTO was unreachable); fputc no longer drives USART6 (printf corrupted STATUS frames). Both retrofit.c copies. Keil rebuild r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
    [retrofit.c, usart.c]
2026-09-08 fix(batch2): boot knives-up (last_tool_ms==0 not fresh), ESTOP enforces SW_Stop brake @1kHz, AUTO steering takeover (angle=0), LIFT=NAV0+TOOL-up recoverable semantics, bridge valid_frame CRC gate; 42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
    [main.c, retrofit.c]
2026-09-08 fix(r5 rework): steering takeover moved before send_angle (was dead code after path_plan rewrite); SW_Stop writes estop-gated + getter; explicit knives-up at init; bridge exact-length + optional sour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
    [main.c, retrofit.c]
2026-09-08 fix(r6): add missing retrofit_estop_latched() impl in both retrofit.c (link regression - patch-script replace silently no-oped); full C symbol link self-check added; source allowlist defaults to conf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
    [config.yaml, retrofit.c]
2026-09-08 build: Keil rebuild verified - 0 errors, 61 legacy warnings, Code=44616, hex regenerated; build log archived; ledger/AGENTS status updated
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2026-09-10 docs: X5 bring-up execution checklist (burn/SSH/UART/B2/B7/B8) — hardware arrived, B7 switched from Pi to RDK X5
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2026-09-10 feat(tools): stream_view.py — TCP multipart MJPEG viewer (UDP+FFMPEG path dead: OpenCV5 FFMPEG can't open mid-stream UDP TS); fix udp_view paste corruption
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2026-09-11 docs: bridge bench verification — O1-5G pair, ping 0% loss, TCP MJPEG 104-225ms over wireless (5 samples), eth0-reboot lesson
2026-09-12 fix(review H1/H2.6/H4.5): asset-safe split_dataset + frozen label dict (peony/shaoyao), protocol extract_one remainder keeps partial frame, bridge rest fix; ledger section H; 60 tests
    [protocol.py]
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2026-09-12 fix(docs): correct X5 power — kit adapter is 5.1/9/12/15V USB-C PD (12V legal via PD negotiation), not 5V-only; restore plan B (48V->PD source module); register Hw-15/Hw-16 in ledger; add fact-author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
2026-09-12 fix(docs): X5 = 5V/5A per manual; 5V/5A is PD-only (5V/3A default) so PD negotiation + e-marker 5A cable REQUIRED — removes the 'direct 5V drop, skip PD' contradiction; add PD-meter verification step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
2026-09-12 fix(docs): X5 power final per manual — USB-C port1, 5V/5A adapter required; drop over-strong 'must PD' claim (manual sets no PD requirement), keep 5A-capable cable as the hard constraint; ledger Hw-1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
2026-09-14 migrate zcode→qoder workspace; fix R1+R2 (asset safety), 64 tests
    - R1: train_m.py SAVE_WEIGHT_DIR no longer writes to read-only JetBrains repo;
    now workspace model_data/weights, matching pc/perception.py load path.
    - R2: split_dataset.py refuses re-run into non-empty target without --force
    (prevents train/val/test contamination) and refuses source/output overlap.
    - tests: +4 regression (R1 static guard; R2 non-empty/force/overlap).
    - carries qoder-authored docs: v0.9 defense-first spec + vehicle power list v1.
    - origin removed: qoder is an independent working copy of zcode @ ab3f4b1.
2026-09-14 fix(review 09-14 R1/R2): train weights write to workspace (was read-only repo — output path audit completing P1-7); split_dataset refuses non-empty targets without --force (7/4/3 cross-set repro); le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
2026-09-14 fix R3+R5+R6+H5.5 (re-review 2026-09-14); 71 tests
    - R3: TCP multipart MJPEG now in the live path — new common/mjpeg.py
    (latest_jpeg + reconnecting iter_frames), pc/main.py _from_stream uses it,
    vehicle/stream_pi.py emits tcpserversink multipart, config.yaml -> RDK X5
    (ttyS1 / pc_ip 192.168.127.100 / stream TCP). Replaces the dead UDP-TS path.
    - R5: status_rx tracks last-good time + monotonic seq (old seq can't overwrite)
    + stale()/silence alarm; main.py surfaces MCU:STALE in HUD + warning.
    (AUTO gating on MCU-freshness deferred to the H2 control-contract round.)
    - R6: split_dataset default out-root -> model_data, matching train_m input.
    - H5.5: train_m test branch used val_* fro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
    [config.yaml, mjpeg.py]
2026-09-14 v0.9 §3.1: resolve R4 steering strategy = front-wheel Ackermann + rear straight
    Per user: thesis need not feature steering; keep it self-consistent with the two
    walking-control reference theses. Steering -> implementation detail, not an
    innovation point; §8 innovation-2 reframed accordingly. Rear wheels straight
    by construction removes the Ackermann4WS non-common-ICC bug (re-review R4);
    add mirror / straight-limit / rigid-velocity unit tests. Declared as an
    explicit 开题 adjustment (front-steer + rear straight; 4WS in-place = demo/展望).
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2026-09-14 fix R4: Ackermann4WS -> front-wheel Ackermann + rear straight; +5 geometry tests
    Old rear counter-steer made the 4 wheels not share one ICC (re-review: ICC
    differ by track width). Rear angle now 0 by construction; front Ackermann
    about ICC=(0,R); speeds = omega*radius to that ICC. Tests assert common ICC,
    straight rear, rigid speed field, left/right mirror, straight limit.
    Matches v0.9 §3.1 (front-steer + rear straight; steering = impl detail).
    [nav_control.py]
2026-09-14 fix(H2.1-H2.4): vision_loss AUTO-only (+4 tests, kills MANUAL->LIFT->NAV->AUTO authority loss); AUTO arbitrates Switch_direction=0 at 4 send_angle sites; retrofit_sbus_ok() + MANUAL SBUS-stale wheel 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
    [main.c, retrofit.c]
2026-09-14 docs: authorize thesis_cau subtree as writable exception (qoder R7/H4 text fixes) — scoped, surgical commits, HEAD report; ledger H4.1 status
2026-09-14 fix(H2.5): bridge splits last-real-PC vs last-inject timestamps — injections rate-limited (500ms) and can no longer extend their own window (review repro: 139 inj/70s → now stops at 60s expiry); ledg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
2026-09-14 thesis(qoder copy): apply R7/H4 text fixes — ch04 front-Ackermann+rear=0 (R4), NAV2/steer-fault -> design+Hw-11 precondition, stepper->servo (ch02/ch04), ch03 mIoU peak口径 (epoch76=0.7459)
    Working copy of chucao_prj/thesis_cau under qoder per user option 2; chucao_prj
    left untouched (read-only). Sync-back to chucao_prj pending.
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2026-09-14 H4.6 (option A): method-material §4.x.1.3 corrected to 2nd-order closed loop
    Drop the wrong '3rd-order characteristic polynomial' claim: under the stated
    assumptions psi is an intermediate variable that cancels -> e_ddot+(2v kd/W)e_dot
    +(2v kp/W)e=0, stable iff kp>0,kd>0. Model uses (e,edot) two states, no separate
    heading state. Accurate code note: wheel_speeds = k_lat*e + k_heading*heading_err_rad,
    main passes heading=0 so damping is currently inactive (k_heading<->kd*v); flagged
    as §13 to-implement, thesis must not assume PD active. ch04 has no such claim (no edit).
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2026-09-14 docs(ledger): close H2.7/H2.8 — fixes verified in mainline (nav_geometry tests, status_rx stale/seq)
2026-09-14 fix(H2.3): add retrofit_sbus_ok to the KEIL PROJECT retrofit copies (大车proj/HARDWARE/retrofit) — previous patch only touched the top-level reference copy, link failed (same dual-copy trap as r6)
    [retrofit.c]
2026-09-14 H1.3/H1.7: grouped train/val/test split + frozen split_manifest.json
    - split by group key (video/plot/day filename prefix, --group-delim, default '_')
    so no group straddles sets -> closes the random-per-frame neighbour-leak that
    inflates mIoU (Astra/re-review H1.3).
    - writes split_manifest.json (seed, group->set, counts) = frozen, reproducible
    split for training + thesis audit.
    - <3 groups -> loud warn + fall back to per-file split (no silent all-train).
    - --no-group keeps legacy behavior.
    - tests +3 (group_of, no-straddle, manifest). 89 pass.
    - NOTE for C1: autumn filenames must encode group prefix (video/plot/day) for
    grouping to engage; naming convention -> 秋季采集清单 (zco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
2026-09-14 sync qoder firmware to mainline — fix Keil L6218E undefined retrofit_sbus_ok
    Root cause: git checkout/rebase with the Chinese path (大车proj/大车) silently
    no-op'd, so qoder's project-compiled HARDWARE/retrofit/retrofit.c (+ top-level
    retrofit.c/.h, main.c) lagged zcode mainline and lacked retrofit_sbus_ok (H2.3)
    -> Keil link error. Copied the 5 firmware source files from mainline (I have no
    independent firmware edits); firmware now == zcode a972ab7.
    ACTION: Keil Rebuild again — expect 0 Error (retrofit_sbus_ok now defined).
    [retrofit.c]
2026-09-14 H2.3 fix: gate SBUS heartbeat on frame validity, not every USART IDLE event
    Tracing who writes sbus_last_ms (the new retrofit_sbus_ok() freshness
    source) showed retrofit_notify_sbus() was called at the head of
    USART1_IRQHandler, before the 0x0F-header + XOR check. A broken-but-
    floating SBUS wire still clocks bytes, so garbage refreshed the heartbeat
    and the MANUAL fail-safe never armed — it only covered the "receiver off"
    case, not the "wire broken" case its own comment claims.
    Move the call inside the validated branch. Deliberately NOT gated on the
    receiver flag byte rec_sbus_data[33]: the legacy code assumes >0 = healthy,
    which is the opposite of the SBUS spec, LOCK_FLAG is write-onl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
    [telecontrol.c]
2026-09-14 docs(缺口清单+AGENTS): 写清"做完/没做"状态板，并修正已过时条目
    用户要求把做完的和没做的直接落到清单里，不在聊天里报。
    新增 缺口清单.md 顶部『📊 总览：做完的 / 没做的』板（按 AGENTS.md
    审查清单第 5 条的 已设计/已编码/已台架/已田间 四态分列）：
    - ① 🟢 已做完并留证（含本轮固件：0 Error / Code=44840 / map 内符号真定义）
    - ② 🔴 已编码但必须上台架才算完 —— B1..B8 + H2 组合场景 ①-⑦ + Hw-17 逐项通过标准
    - ③ 🔴 明确没做，按"只能用户做 / 我能做但被前置卡住 / 等 zcode merge"三类分列，
    不含"部分完成"表述（H2.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
2026-09-15 组会汇报 deck（2026-09-16）：18 页 Route C 可编辑 + 每页数字的溯源合同
    明天组会用。按开题报告口径讲：除草机构选型 → 总体设计与控制原理 → 进土深度开放问题 → 进度。
    用户已明确：Route C 回退、16±2 页、不放图（现场展示）、选型按"已完成"呈现、深度问题带方案抛、
    进度照实但简写、不列评审 bug 清单。
    内容不是临时组织的：paper_analysis.json 是证据合同（13 源文件 / 17 条溯源记录 / 16 条证据链 /
    18 页），validate_paper_analysis.py 通过；deck 由 build_pragmatic_fallback_pptx.py 生成，
    结构校验 0 issues；PowerPoint COM 导出 18 张 PNG 逐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
2026-09-16 组会汇报 deck 第 2 版（09-16）：删进度页、第13页改直白版、15/16页重构为挂草与撞石主动抬刀
    汇报人自己改了 pptx，先把他 6 处手改回写进 plan 作为权威内容再重出，避免覆盖：
    汇报人姓名、行距 30~40cm、坡地 0~15°、删"未登记项"行、第 9 页去 mIoU 数字、
    第 10 页删两条、第 11 页删"IPM 硬编码"、第 16 页判定依据去前缀。
    结构变更：
    - 删第 17 页进度表（汇报人要求）；结尾页保留，导航末段改名"小结与讨论"，
    三条讨论问题放回结尾 → deck 18 → 17 页
    - 第 13 页标题改"中间刀还不能叫闭环：刀到位了，相机看不出来"，五条 b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
2026-09-16 组会 deck 第 4 版：删掉结尾页三条讨论问题（汇报人删过的不再加回）
    09:57 那版结尾页只剩"汇报完毕，敬请批评指正！"一行，AGENT_CLOSING_META 是汇报人删掉的，
    我上一轮重出时把它当自己的内容写了回来 —— 同一类错第二次（上一次是 13 处红字 takeaway）。
    现在 closing 的 metadata/bullets 全部移除，构建后确认 AGENT_CLOSING_META 与 AGENT_TAKEAWAY
    形状数均为 0。
    三件想请组会定的事不再上页面，改为只记在 gen_map.py 的『口头要提的三件事』一条里
    （进土深度走哪条路 / 铲幅何时补测 / 春季田块书面确认）。
    顺带把溯源表的生成逻辑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
2026-09-21 E1 修复：MCU 重启序号重新同步 + 分组划分不再产出空测试集（09-21 复审）
    两个都是我自己写的 bug，09-21 codex 复审复现后确认成立。
    ① pc/status_rx.py —— MCU 重启后 STATUS 长期不可用
    旧逻辑只认更大序号、无会话重置。更正我上轮写进方案的措辞：不是"永久拒绝"，
    按 16 位回绕，重启前序号 ≥32769 时下一帧即恢复，最坏（≈32768）约 27 min 无 STATUS。
    修法采纳复审意见：**"连续 ≥50 帧被拒"不足以证明重启**（同一旧帧重复 50 次也满足），
    改为要求这 50 帧序号**互不相同且单调递增**，且 stale() 成立 → 判为重新同步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
2026-09-21 秋季执行序列 S1-S4 落进 v1.0：搬运是一次性事件，可迁移项必须先做完
    汇报人 09-21 说清现状：控制栈（大板+X5+相机+网桥）尚未装到任何车上；先装上代车
    （3.25 m）验证"能不能用电脑控制、有什么问题"，没问题再搬到真实车；真实车在地里、
    不好运。
    这条约束的性质不是"进度紧"，而是**搬运是一次性事件**——不能反复拆装试错。所以
    v1.0 新增 §4.2 把它翻译成序列与出门判据：
    - S1（本周，上代车）装车 → B1 烧录 → B2 对拍含 SBUS 两子情形 → 电脑控得住、失联停得下
    - S2（上代车，平地）拉平行标记带做地面基准，跑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
2026-09-21 E2③④：SBUS 必须收满 35 字节才算有效帧；视频读取改成有界轮询，控制循环不再被 socket 拖住
    E2③ telecontrol.c:142 —— 有效帧判据由两条件变三条件：长度==SBUS_DATA_LEN(35)
    加在帧头 0x0F 与 XOR 前面。原来的病：XOR 循环无条件读 bytes 1..33 与 [34]，短帧
    （部分帧）时数组里留着上一帧的旧尾巴，而旧尾巴本身是有效数据，于是帧头与 XOR 可能
    同时通过、16 个通道字却是两帧的混合。与 H2.3 同源：收不全就不算收到。
    GBK 字节级修改，前后缀逐字节比对通过（汉字 469 个不变）。
    UV4 -r：0 Error / 60 Warning（基线 61，少的正是 "UART1_Rec_Len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
    [mjpeg.py, telecontrol.c]
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2026-09-21 统一"低机位"口径；采集清单那条 0.9 m 装机要求是真的会误导人改机位
    Hw-20 已现场确认相机镜头离地 100 cm（轮心才 30 cm），ch02:23 的"低机位"是错措辞。
    问题不止措辞：docs/秋季图像采集清单.md §1 写着"相机装到 0.9 m 前视低机位"，
    照它做就等于为了采集去改装机位 —— 而这条自己的理由是"采集域=部署域"，
    改完两个域反而不一致了，秋季素材跟实车感知不是同一个分布。
    改为：不许为采集另装机位，按实测 100 cm 真机位拍，俯角留给 M11b 实测。
    缺口清单 C3 标题与台账 Pc-1 的验证方式同步改口径，并在 Pc-1 补一句：
    标定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
2026-09-22 修上一批改错了的一头：F3 场景占的是 ⑧ 不是 ⑦；⑦ 从一开始就属于"已知遗留"
    zcode 放行批里让我改一行当前状态，改的过程中查出三件它和都没发现的问题：
    1) 抢号。第 455 行那份"组合场景验收清单（H2 关闭条件，不以测试数为准）①–⑦"才是
    权威清单，AGENTS 第 44 行与 v1.0 §4/§7 说的"组合场景 ①–⑦"全指它，它的 ⑦ =
    已知遗留 send_angle。我上批把 F3 编成 ⑦ 塞进 B2，又把"⑦已知遗留"改名让位——
    **让位让错了对象**：该改号的是我新加的那条。现在 F3 = ⑧，原 ①–⑦ 一字不动，
    权威清单同步补第 ⑧ 项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
2026-09-22 docs(review checklist): two more rules from 09-21 lesson 4 — self-fix diffs get same rigor; zero-hit self-check output is evidence to explain, not a pass
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2026-09-22 docs(review checklist): replace per-form exemption with block-exclusion — rule examples live in an excluded block, all invariants absolute (qoder 09-22 self-reference diagnosis accepted)
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2026-09-22 X5 清单：B1 认版三处 + UART 换线前置两件 + 9100 互斥（出门前的跑法说明）
    - §4 B1：删掉"Code=44616"的旧注（09-08 那版，会让人怀疑手上 hex 不是最新的），
    换成 09-22 实测三处：build_log 末行 0 Error/60 Warning、Program Size
    Code=44848、map 内 retrofit_sbus_ok @0x0800886b。
    ⚠️ 并写明 `OBJ/` 在 .gitignore:11 —— **hex 不在版本库里，只活在构建它的那台机器上**，
    丢了要自己重建，重建命令按现核过的两条路径写全（UV4.exe 与 PWM.uvprojx 都存在）。
    - §5 换线：把接线图 §5 风险点 1 与 §7 未勾的两项提到动作前面 —— R23/R13 选型
    电阻哪个有焊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
2026-09-23 Hw-23 二次实测修正归因：两档签名相同 ⇒ 标志位假设作废，改指前轴整体反相
    作者同日补测：横向与纵向**都是**"推前进时前轮向后、后轮向前"，与模式无关。
    这一个事实同时否掉两个候选：横向带负号置换只在横向档生效；我首测提的
    "横向标志位未回位"预测两档行为不同。两者都解释不了"两档签名完全相同"。
    新归因（按排查代价递增）：a) 前轴电机控制器的方向设置（拨码/跳线/参数）
    b) 前轴动力线极性 c) 大板 TIM8 通道→轴映射与这台车不同。
    判据：推后退是否整体镜像（是=符号，否=通道错配）＋控制器铭牌/拨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
2026-09-23 Hw-23 补偿落地：前轴方向引脚极性取反（FRONT_AXLE_DIR_SWAP，可回滚）
    作者 09-23 现场指示"直接改固件行走电机正反"。改法不是翻 PWM 数值：
    Out_Pwm 的方向由每轮方向引脚带（Roll_xx_Dr，左右两侧极性本就镜像），
    翻数值会让四轮符号变成"前后相反"，落进三个分支都不匹配的空档，
    车会保持上一条命令——比现在更糟。正确补偿 = 四个分支里把前轴两轮的
    方向引脚极性取反，共 8 个赋值，全部放在 #if FRONT_AXLE_DIR_SWAP 里，
    回滚 = 宏置 0 重编译，不留散落负号。
    证据链：UV4 -r = 0 Error / 60 Warning / Code=44848（与改前同尺寸，
    仅常量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
    [car_control.c]
2026-09-23 撤回一条我自己转述错的指导：换网桥**不用**改 pc_ip
    （标题重复了上一条的措辞，实际内容见下——commit message 写错标题，
    正文与 diff 是对的；如需可 amend，但内容以本条正文为准。）
    作者再测报为**单轮（左前）反相**，与"整轴镜像"假设不相容。我那次 8 处
    方向引脚补偿是在这个假设上写的，留着它测出来的表会混进我的假设，
    分不清哪个是车的真相 ⇒ 宏置 0 重编译，回到厂商极性作测量基线。
    0 Error / 60 Warning / Code=44848，hex 09-23 15:31（认版 mtime 随之更新）。
    同时把"有没有后退"这条查准并记进台账 Hw-23 ⑧：油门带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
    [car_control.c]
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2026-09-24 Hw-23 补偿落地：前轴方向引脚极性取反（FRONT_AXLE_DIR_SWAP，可回滚）
    （标题笔误，与 2a62b58 撞了；本条实际内容是下面这段，请以正文为准。）
    实板补测：R15、R16 **并未焊接**（厂商注写"默认焊接"，按铁律以实板为准）
    ⇒ 撤回上一条"拆 R15/R16"待办。485 芯片的 TTL 侧本来就断着，作者焊 R25/R26
    之后正是厂商预留的 TTL 直通配置，没有"两个驱动抢 PC7"的问题。
    待证点转移到别处：作者用 T6 的 **A_4、B_4** 走 TTL，而这两个 pad 也是 U7 的
    A/B 输出落点。若 U7 在位带电、DI 因 R15 开路而悬空，自动换向器件可能仍在
    驱动 A/B。三条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
2026-09-28 执行清单加 §0A：每次接 X5 必做与不用重做，第 3 步"改配置"降为正常情况下不用动手
    作者现场问"每次用电脑、接上 X5 之后要重新操作哪些步骤"——这个问题本来就该有一份
    清单回答，而不是每次重新想一遍。分成三块写：
    不用重做：X5 的 eth0 静态 .10、~/qoder 那份代码（只在我改了 vehicle/ 或 common/ 之后
    要重新 scp；tools/ 与 pc/ 是笔记本侧）、config.yaml、已烧录的固件。
    每次必做（按顺序）：ipconfig 确认本机是 192.168.127.100 → pkill cat（cat 和 bridge
    同读一个串口会把帧撕成半截）→ **sudo** python3 bridge.py（不会自启，普通用户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
2026-09-28 Hw-27 复现成立 + 新增 Fw-14：ESTOP 锁存没有清除路径，探针单发一条会把自己锁死
    Hw-27 补"复现"这一步：接收机供电插着跑 649 秒 = 重启重同步 53 次、好帧 9907、坏帧 0，
    而拔掉那轮是连续的 ⇒ "接收机供电在不在 = 有没有复位循环"这一级因果立住。
    但**周期不稳**：649/53 ≈ 12.2 秒一轮（其中发帧约 9.4 秒），早上是 2.95 秒 ⇒ 不是固定 RC
    弛张定时，机制仍未定；作者这一轮"通电几秒后拨了一下遥控"，动作负载参与那条留着不撤。
    同一份 CSV 的算术自证今天那个修复生效：行数 10013 − 好帧 9907 = 106 = 53 对 gap 行，
    与 53 次重同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
2026-09-29 反向探针加 --serial：USB-TTL 直连大板时一边发一边读，配 3 条不需要硬件的测试
    作者要"直接用电脑连大板看能不能通信"，用来把 Hw-1 的反向问题拆成"板子收不进"还是
    "X5 发不出"。现有探针只会走 UDP，所以给它加一条串口路，而不是再写一个新工具
    （两个工具各发一套帧，迟早两套说法）。
    `--serial COM6` 时的行为：不 bind、不发 UDP，打开串口按同样的 --every/--count 发帧，
    同时起一个读线程把大板吐出来的 STATUS 解出来——**这样不需要第二个窗口当显示器**，
    少一次"我到底该看哪个屏"的错。发完再读 --watch 秒（默认 8）等 m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
2026-09-29 Fw-16：USART6 的 RX 被两个脚同时映射（PC7 与 PG14），厂商那颗还引到 T7 并上拉
    起因是作者问"是不是之前没改波特率所以发不了"。先否掉波特率：main.c:151 是
    uart_init(115200)，main.c:163 的 retrofit_init 也是 115200，而同一颗 USART6 只有一个
    BRR、收发共用——发的那一半已被证明在 115200 上干净（X5 坏帧 0、20Hz），收不可能单独
    "波特率不对"。但这个方向问对了，问题在引脚映射上：
    厂商 uart_init 在 retrofit_init **之前**跑，把 PG9+PG14 设成 AF8=USART6 且 GPIO_PuPd_UP
    （usart.c:85-94）；我们的 retrofit_init 只把 PC6+PC7 设成 AF8（retrofit.c:369-383），
    **没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
2026-09-30 记录器：证据文件不再被同分钟重跑覆盖，坏帧洪水也能落 ALARM（+2 回归，基线 159）
    承接 codex 09-29/30 复审"上轮问题复核"里仍挂着的两条，本次改掉：
    1) 证据防覆盖。BenchLog 原来用 open(path, 'w')，而默认目录只到分钟
    （results/bench_YYYYMMDD_HHMM）⇒ 同一分钟重跑一次就把上一份证据静默清空，
    而台账里可能已经引用过那个路径。改成 'x'（独占创建，已存在就抛 FileExistsError）
    + 新增 unique_path()：主循环先挑一个不存在的名字（bench_log_2.csv、_3.csv…），
    并在另存时打印一句说明。宁可换名，绝不覆盖。
    2) ALARM 的盲点。rx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
2026-10-09 计划正文抄了检查器要数的基线符号，害它自 c1b956e 起长红：改措辞，基线一个数字没动
    问题：`c1b956e`（两份实施计划成文）把 `check_doc_invariants.py` 要数的那个
    "圈号–圈号"符号**原样抄进了计划正文**，共 4 处：
    2026-10-08-e3-batch-1a-firmware.md:900 / :920
    2026-10-08-e3-batch-1b-pc-tools.md:1756 / :1773
    后果：`tests/test_doc_invariants.py::test_real_repo_is_clean` 从那条提交起就是红的，
    检查器退出码 2、命中 6 → 10。批 1b Task 1 的实施者如实报了"基线不是 159 passed，
    HEAD 实测 158 passed / 1 failed，且早于本任务"，没有替我掩盖，也没有偷偷把它改绿。
    为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
2026-10-09 许可位改 fail-closed 并补上 LIFT 的回归钉：修任务审查 Important #1/#2
    E3 批 1b 第 2 步返修（对 a1579e8 的任务审查，两条 Important，范围仅 pc/wire.py 与 tests/test_wire.py）。
    Important #1：permit 是唯一的"执行许可"闸门，旧写法
    `if permit == GATE_N: ... else: <GATE_F 语义>` 是 fail-open——实测 permit=0 / None / ''
    / 'gate_f' 甚至 'gate_n'（安全档的名字串）全都返回 TOOL(off=5.0, lift=0x00)，即门 N 的
    样机静默落刀 + 横移，而固件侧 REJECT_PERMIT 要到批 1a 烧录后才存在。改为
    `elif permit == GATE_F: ...` + `else: raise ValueError('unknown permit %r' % permit)`。
    Important #2：LIFT 专属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
